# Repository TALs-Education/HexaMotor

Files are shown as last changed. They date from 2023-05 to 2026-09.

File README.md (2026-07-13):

# HexaMotor
### Position & Velocity Control Experiments

## Overview

HexaMotor is a hands-on experimental platform designed for university-level education, emphasizing the nuances of position and velocity control. 
Powered by Simulink, it not only generates the code for the embedded setup but also serves as an intuitive interface. 
This design choice allows students to concentrate on control implementation rather than the intricacies of code writing. 
With a foundation built around a DC motor, HexaMotor offers a tangible experience of system dynamics and control.

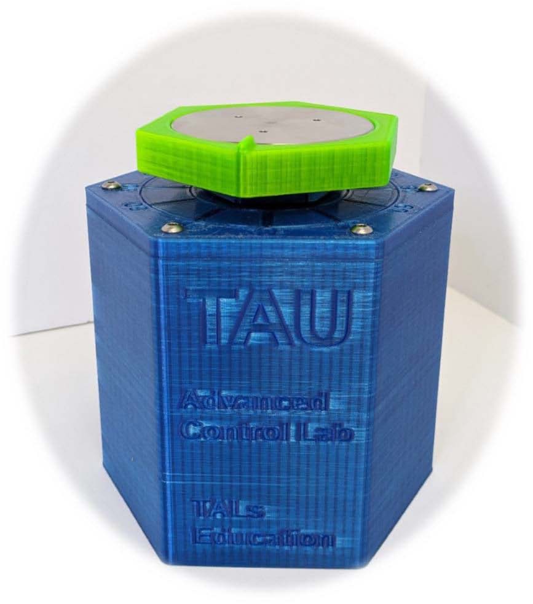
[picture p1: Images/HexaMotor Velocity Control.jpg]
HexaMotor Setup


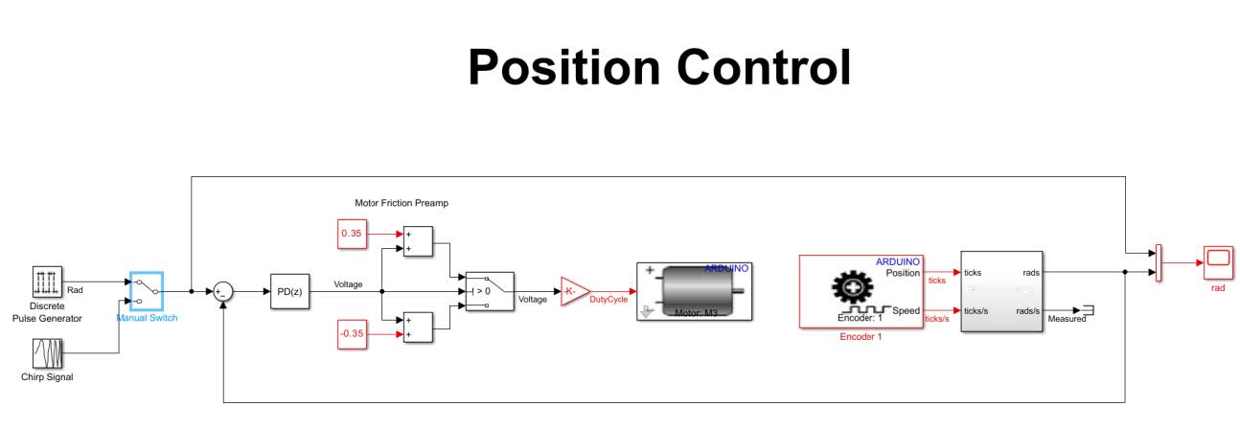
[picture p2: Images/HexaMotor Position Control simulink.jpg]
HexaMotor Simulink Model


## Velocity Control Experiment

### Subjects Covered

- **Introduction to DC Motor Dynamic Equations**
- **Coulomb Friction Identification and Handling**
- **System Identification Using Open Loop Step Response**  
- **System Identification Using Frequency Response**
- **Velocity Control Implementation: Proportional & Proportional-Integral Control Loops**
- **Controller Performance Under Load**

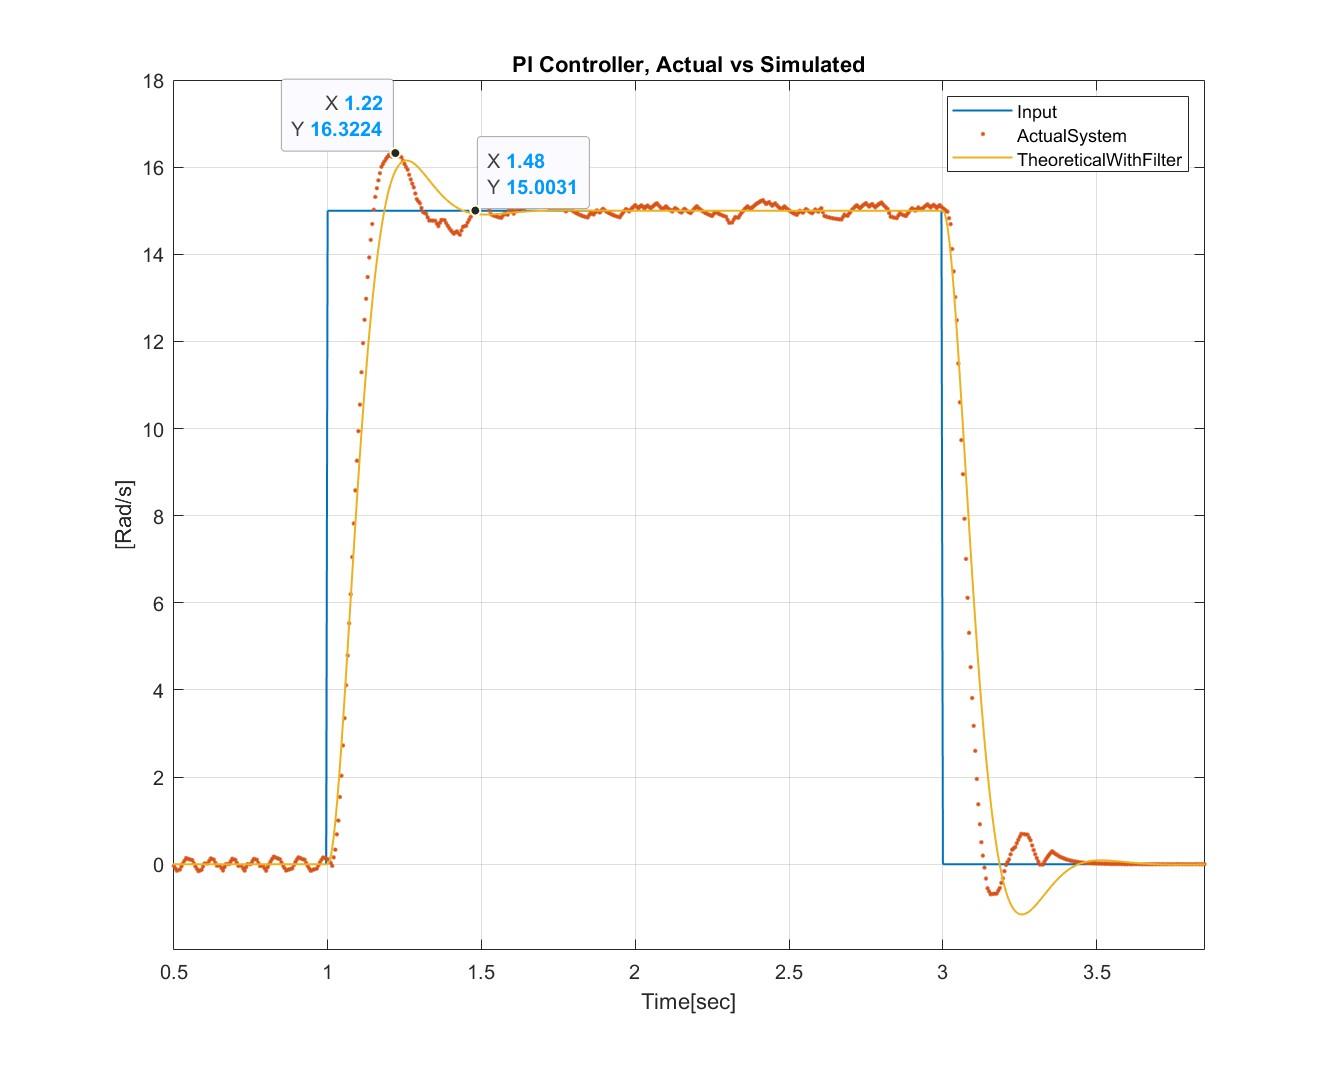
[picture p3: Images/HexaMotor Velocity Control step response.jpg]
Plot for Close Loop Step Response


## Position Control Experiment

### Subjects Covered

- **Introduction to Second Order Systems**
- **Coulomb Friction Identification and Handling**
- **System Identification Using Position Close Loop Step Response**  
- **System Identification Using Position Close Loop Frequency Response**
- **Position Control Implementation Based on Second Order System Modeling**
- **Lead-Lag Compensator Controller Design and Implementation**
- **Force FeedForward Example: Compliant Motor Control**

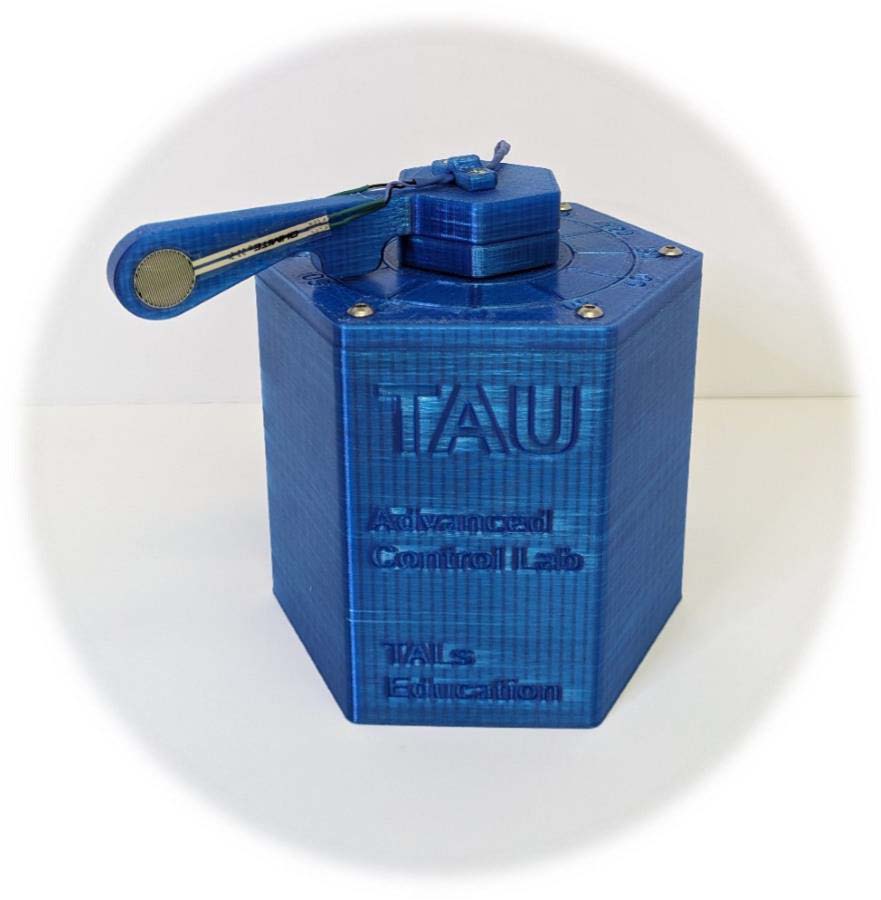
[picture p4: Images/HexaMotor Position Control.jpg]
Force sensor Image
  

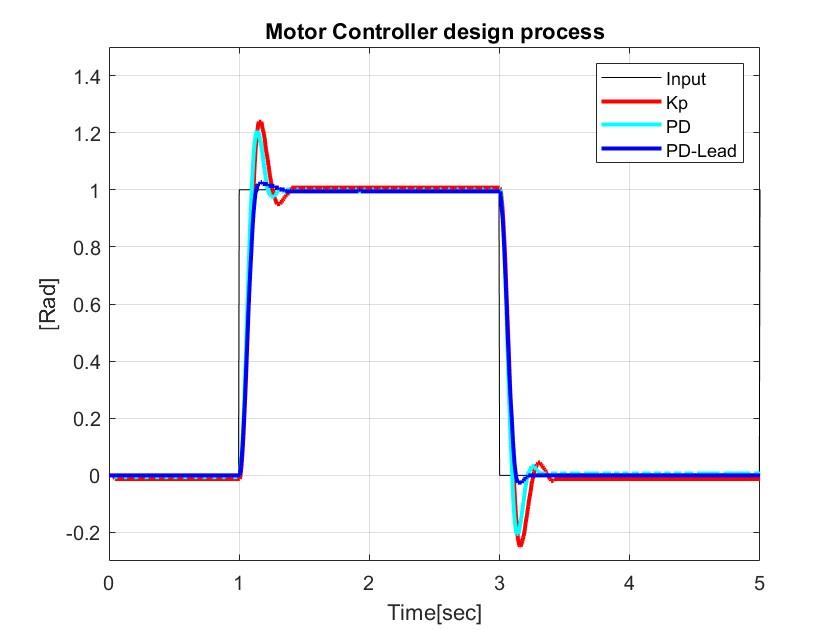
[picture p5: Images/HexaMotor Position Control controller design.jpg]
Plot for Position Close Loop Step Response
  

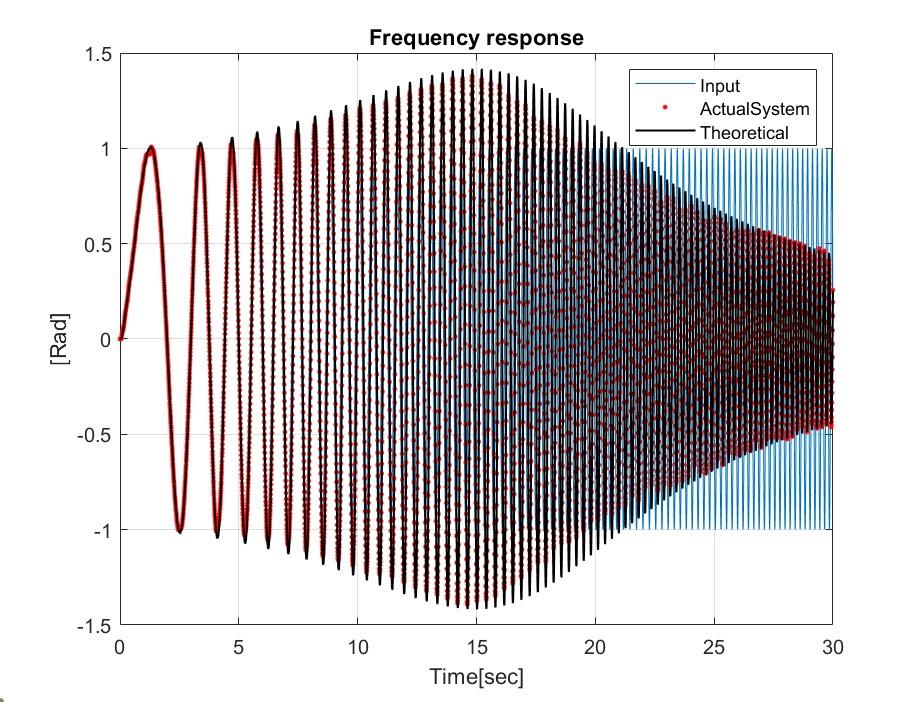
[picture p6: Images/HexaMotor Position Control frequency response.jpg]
Plot for Frequency Response, System Identification
  
  
## Setup & Usage

### 4.1. DC Motor

This gearmotor is a combination of a 12 V brushed DC motor with a 20.4:1 metal spur gearbox. It also incorporates a 48 CPR quadrature encoder on the motor shaft, providing 979.62 counts per revolution of the gearbox’s output shaft.

- **Product page**: [Pololu Gearmotor](https://www.pololu.com/product/4883)
- **Data Sheet**: [Pololu 25D Metal Gearmotors PDF](https://www.pololu.com/file/0J1829/pololu-25d-metal-gearmotors.pdf)

### 4.2. Arduino Boards

The MKR Motor Carrier is an add-on board designed for MKR to control servo, DC, and stepper motors.

- **MKR Zero**: [Arduino MKR Zero Documentation](https://docs.arduino.cc/hardware/mkr-zero)
- **MKR Motor Carrier**: [Arduino Store - MKR Motor Carrier](https://store-usa.arduino.cc/products/arduino-mkr-motor-carrier)

### 4.3. Simulink Support Package

Utilize MATLAB and Simulink Support Packages for Arduino® hardware to interactively communicate with your Arduino. With Simulink, you can also perform model deployment for standalone operations on Arduino boards.

- **MathWorks Support**: [MATLAB & Simulink for Arduino](https://www.mathworks.com/hardware-support/arduino.html)

### 4.4. 3D Model – Fusion360

The entire setup has been designed in Fusion360 as an open-source project meant for educational applications.

- **Fusion360 Project**: [HexaMotor Fusion360 Model](https://a360.co/3Xp2fAi)

### Usage Instructions

For detailed instructions on setting up and running experiments, refer to the provided manuals:

- **Part1: Velocity Control**: [HexaMotor Velocity Control Manual (PDF)](HexaMotor_V01/HexaMotor%20Velocity%20Control.pdf)
- **Part2: Position Control**: [HexaMotor Position Control Manual (PDF)](HexaMotor_V01/HexaMotor%20Position%20Control.pdf)

### Demo Video
- **YouTube:** [HexaMotor Frequency Reponse](https://youtu.be/2T9OHVP0HO0?si=b-_GwjwfcQOfvFEu)

## License

This project is licensed under the GNU General Public License v3.0 - see the [LICENSE](LICENSE) file for details.

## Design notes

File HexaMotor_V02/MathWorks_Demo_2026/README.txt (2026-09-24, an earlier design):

HexaMotor - MathWorks Demo 2026 (MATLAB R2026a)
===============================================

Open this folder as the MATLAB current folder, then run the Live Scripts in this order:

1. HexaMotor_SysID_Demo.mlx       Motor equations, closed-loop 2nd-order identification (chirp sweep),
                                  velocity step Kp=1/Ki=0, PI design for 30 % overshoot at 200 Hz.
                                  Saves the identified model as HexaMotorModel (workspace + HexaMotorModel.mat).
2. HexaMotor_LeadLag_Demo.mlx     Advanced: PD + lead compensator (PM -> 60 deg) on the position loop,
                                  step and frequency responses, Bode shift. Uses HexaMotorModel.
3. HexaMotor_StepVsFreq_Demo.mlx  Sub-demo: open-loop step (bump test) vs. frequency-response identification,
                                  compared with the closed-loop model from demo 1.

Run mode (dropdown at the top of each script):
  Virtual motor / Recorded sweep - no hardware needed (built-in motor emulator; FrequencyResponse.mat is a real recording)
  Hardware                       - builds and runs the Simulink models on the HexaMotor (Monitor & Tune / external mode);
                                   the model and its Scope open and stream live during each run.

Simulink models:  HexaMotor_Position_Control_V02, HexaMotor_Velocity_Control_V02,
                  HexaMotor_LeadLag_Control_V02, HexaMotor_System_Identification_V02
Sample rate:      200 Hz (the scripts set the workspace variable sampleRate = 0.005)
Manuals:          Manuals/  (Velocity Control V02, Position Control V02)
Graphical lead/lag charts from the manual: LeadLag.m

Editing: change the plain-text sources in LiveScriptSources/ and re-save them as .mlx
(in the Live Editor: open the .m file and use Save As > .mlx). Keep only the .mlx files in this
folder: when a .m and a .mlx have the same name in one folder, MATLAB runs the .mlx.

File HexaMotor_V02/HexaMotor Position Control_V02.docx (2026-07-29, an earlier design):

# Position Control

# HexaMotor

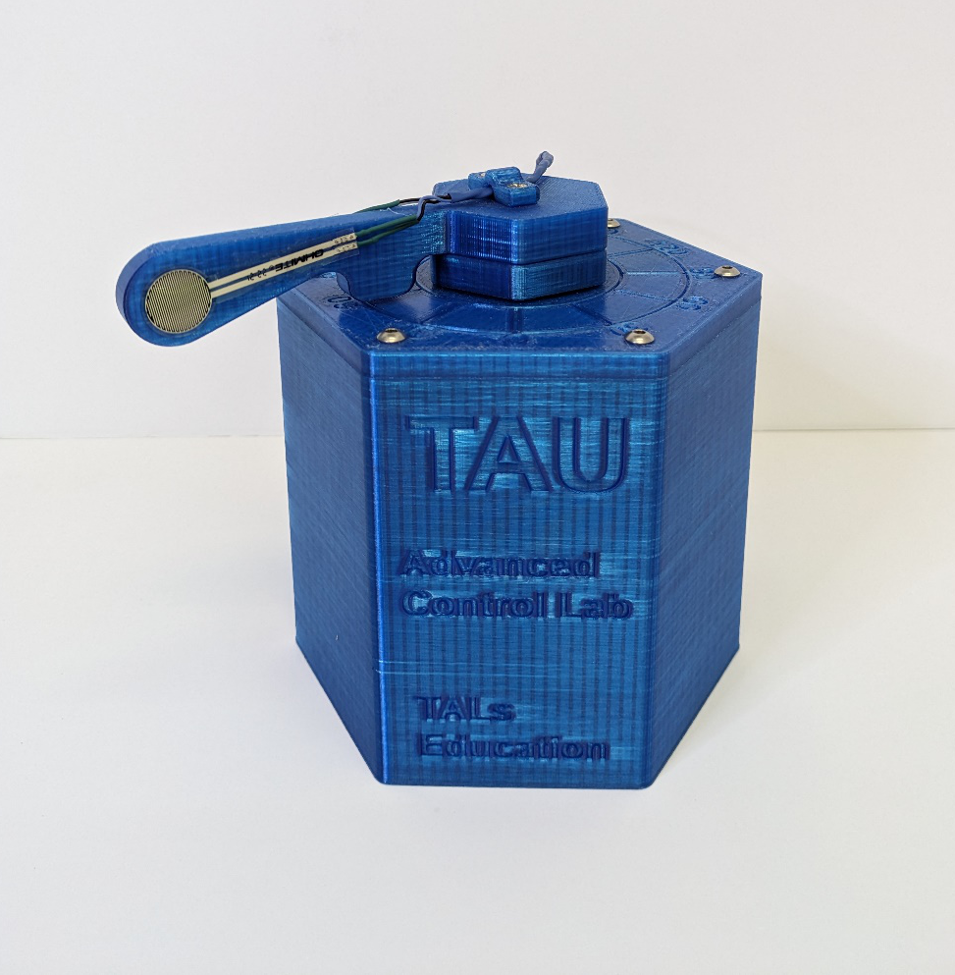
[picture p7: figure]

Experiment objectives:

• Introduction to second order systems.

• Coulomb Friction identification and handling.

• System identification using position close loop step reponse.

• System identification using position close loop frequency reponse.

• Position control implementation based on second order system modeling.

• Lead-Lag compensator controller design and implementation.

# 1. Introduction

In the field of motor control, mastering both velocity and position control is essential for a wide range of applications. While the previous lab experiment delved into the nuances of velocity control and the fundamentals of a DC motor, this experiment pivots to emphasize position control. Position control, vital for accurate maneuvering and precise positioning of mechanisms, demands its own unique approach. This experiment outlines objectives ranging from system identification using step and frequency responses to the design and actual implementation of control strategies.

## First order approximation

While in the previous experiment the full equations of the DC motor were presented and the first-order approximation was derived, in this experiment we will contrinue working with the first-order approximation of the DC motor.

First-Order Transfer Function:

  1.1 G(s)=(K_T)/((RJ)s+(BR+K_T K_b )) ; G(s)=(K_m)/(τs+1)

## Coulomb friction

Recall from the previous experiment that Coulomb friction, which remains constant irrespective of motor speed, contributes to system non-linearity and can pose challenges in control implementation, particularly at low speeds. We identified this friction by applying a controlled voltage to the DC motor, observing the threshold voltage initiating rotation.

## Second order systems

When discussing control systems, a second order system is frequently encountered. It can be described by the standard second-order transfer function:

  1.2 T(s)=K/(s^2 +2ζω_n s+ω_n^2)

Where:

K – is the system static gain.

ω_n – is the undamped natural frequency.

ζ – is the damping ratio.

The system's response is primarily characterized by its damping ratio ζ and natural frequency ω_n

Several performance metrics can be derived from the above standard form:

Percent Overshoot (%OS):

It defines the amount by which the transient response exceeds the steady-state value. For a step response, the percent overshoot is given by: OS=100e^((-πζ)/(√(1- ζ^2))) It should be noted that overshoot occurs only when ζ <1 (underdamped case).

Rise Time (Tr):

The time it takes for the response to rise from 10% to 90% of its final value for an underdamped system. While there's no direct closed-form formula, for many systems with a damping ratio between 0.4 and 0.7, the rise time is approximately: T_r ≈ 1.8/(ω_n)

Settling Time (Ts):

The time for the system response to stay within a certain percentage (usually 2% or 5%) of its final value. It's given by T_s ≈ 4/(ζω_n) for a 2% settling time.

Peak Time (Tp):

The time it takes for the response to reach its first peak. For an underdamped system: T_p = π/(ω_d) where ω_d = ω_n √(1-ζ^2) is the damped frequency.

Natural Frequency ( ω_n ):

It's the frequency at which the system would oscillate if there were no damping (i.e., ζ=0).

## Root Locus

The essence of the root locus lies in its depiction of system dynamics. The locations of the closed-loop poles directly influence the transient response characteristics of the system. By examining the root locus, engineers can predict how changes to the system gain will impact crucial performance metrics such as overshoot, settling time, and oscillation frequency.

The foundation of the root locus method is built on two fundamental principles:

- Magnitude Criterion: At any point on the root locus, the product of the magnitudes of the vectors from all open-loop zeros to that point divided by the product of the magnitudes of vectors from all open-loop poles to that point is equal to 1 (or the gain at that point).
- Angle Criterion: For a point to lie on the root locus, the sum of angles from all open-loop zeros and poles to that point must equal an odd multiple of 180°.

Armed with these criteria, control system engineers can sketch the root locus and use it to select appropriate gains that yield desired closed-loop behavior. Not only does the root locus offer insights into system stability (since poles in the right half of the complex plane denote instability), but it also aids in shaping the system response to meet specified design criteria.

## PID controller

As previously discussed in our prior experimentation, the PID controller is a predominant feedback control algorithm extensively employed in industrial applications due to its efficiacy across diverse scenarios and its systematic tuning methodology.

  1.3 u(t)=K_p e(t)+K_i ∫ e(t)dt+K_d (de(t))/(dt)

The PID controller is characterized by three fundamental components:

Proportional (P): This component yields a control action that is directly proportional to the instantaneous error. The magnitude of this response is governed by the proportional gain

Integral (I): Concerned with the aggregation of error over time, this action aims to nullify any persistent steady-state error.

Derivative (D): This term offers a control action based on the rate of error change, effectively anticipating potential future errors and generating a preemptive control response. In practical applications, a distant pole is introduced to filter out system noise. In our case, the derivative element is filtered by a first-order pole set at half the sampling frequency.

## Lead-Lag Compensator

Lead and lag compensators are essential tools in control theory, particularly in the design of feedback control systems to meet transient and steady-state response specifications:

Lag Compensator: The general transfer function for a lag compensator can be described as:

  1.4 G_(Lag) = (1+τs)/(1+aτs)

Where τ is the time constant and a>1.

Purpose: The primary purpose of a lag compensator is to improve the steady-state response of the system. This is done by adding a pole and a zero to the system. Since the zero is closer to the origin than the pole, the compensator will have a magnitude less than one for most frequencies, thereby reducing the gain of the system and the steady-state error.

Placement: The zero is placed to the left of the pole. The distance between them determines the magnitude of the phase boost, but a lag compensator will not introduce a significant phase lead.

Drawbacks: Lag compensators generally degrade the transient response because they tend to reduce the system bandwidth.

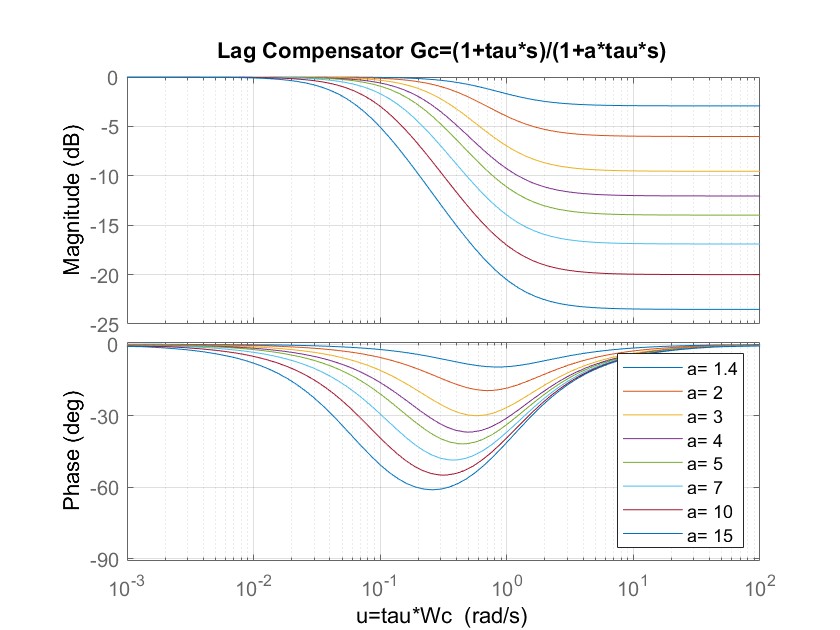
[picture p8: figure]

Figure 1 Lag Compensator plot using LeadLad.m scrip

Lead Compensator: The general transfer function for a lead compensator can be described as:

  1.5 G_(Lead) = (1+aτs)/(1+τs)

Where τ is the time constant and a>1

Purpose: The primary purpose of a lead compensator is to improve the transient response of the system. By placing a pole and a zero in the left half plane, it introduces phase lead to the system, which can be used to reshape the root locus or push the closed-loop poles to desired locations.

Placement: The zero is placed to the right of the pole, introducing phase lead in the frequency range of interest. The amount of phase lead is determined by the distance between the pole and zero and their proximity to the imaginary axis.

Drawbacks: Because of the introduced phase lead, a lead compensator also increases the gain in some frequency range. This can make the steady-state error worse.

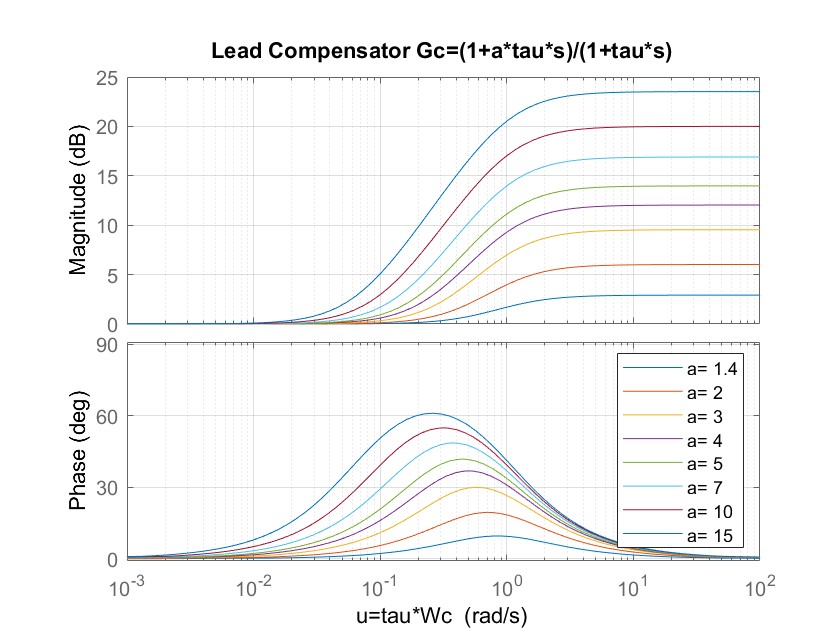
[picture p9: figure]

Figure 2 Lead Compensator plot using LeadLad.m scrip

Design Considerations:

Lag: When using a lag compensator, the goal is often to place the pole and zero sufficiently far from the imaginary axis, so they don't affect the transient response. You place the zero so that the magnitude of the system is unchanged at the crossover frequency.

Lead: When designing with a lead compensator, the goal is often to add enough phase lead to achieve desired transient characteristics without pushing the gain crossover frequency too high.

In practice, combining both lead and lag compensators can offer an optimal balance between steady-state and transient performance in many systems.

Graphical approach for Lead Lag design:

Run the "LeadLag.m"

- The script "LeadLag.m" generates plots associated with the lead-lag compensator design. This includes various curves representing different amounts of phase lead and the corresponding gains for different values of a (since a lead compensator's behavior is determined by its zero and pole locations, which are in turn determined by the parameter a and the time constant τ).

Open-Loop Bode Plot:

- Start by plotting the open-loop Bode plot of the system. From this plot, you'll identify the current crossover frequency ω_c and the existing phase margin.

Determine Required Phase Boost:

- Based on system specifications or desired closed-loop performance, determine how much additional phase you want to introduce.

Iterative Process for Design:

- Use the provided lead graph (generated by the script) to identify a point that provides the necessary phase boost.
- From the corresponding gain graph, note the gain added due to the lead compensator.
- This added gain will shift ω_c in the open-loop Bode plot.
- Now, with this new ω_c the phase requirements might be slightly different. So, you may need to iterate this process to ensure that the final selected values of phase and gain boosts provide the desired performance.

Calculate the Lead Compensator:

- Using the relationship and the equation provided: G_(Lead) (s)=(1+aτs)/(1+τs)
- And given: τ= u/(ω_c) Where:
- τ is the time constant of the lead compensator.
- a is the gain boost and defines the curve.
- u is the specific point on the curve/graph which dictates the amount of phase lead and gain boost introduced.
- ω_c is the new crossover frequency after introducing the compensator.

Implement and Test:

- Once the lead compensator parameters are determined, you can then apply them to the system and validate if the system's response matches your design specifications. You may also need to iterate the design process if the initial compensator doesn't provide the desired results.

This process essentially allows you to design a lead compensator using graphical methods, taking advantage of the insight provided by Bode plots and the relationships between phase lead, gain boost, and compensator parameters.

# 2. Pre Lab

## Second order system identification

Identifying the First Order Transfer Function of a DC Motor Using Closed-Loop Step Response in Position Feedback

In this method, the behavior of the DC motor under position feedback is contrasted with a canonical second-order system, described by T(s)=K/(s^2 +2ζω_n s+ω_n^2) . The benefits of this comparison are twofold. Firstly, second-order systems are thoroughly understood and have been extensively studied, offering a benchmark against which the motor's dynamics can be evaluated. Secondly, essential performance metrics — including overshoot, peak time, rise time, and settling time — can be directly correlated to the system's damping ratio, ζ, and its natural frequency, ω_n .

Armed with these metrics from experimental observations and a known feedback gain, it's possible to determine the inherent characteristics of the DC motor, especially its time constant, τ, and gain, k_m .

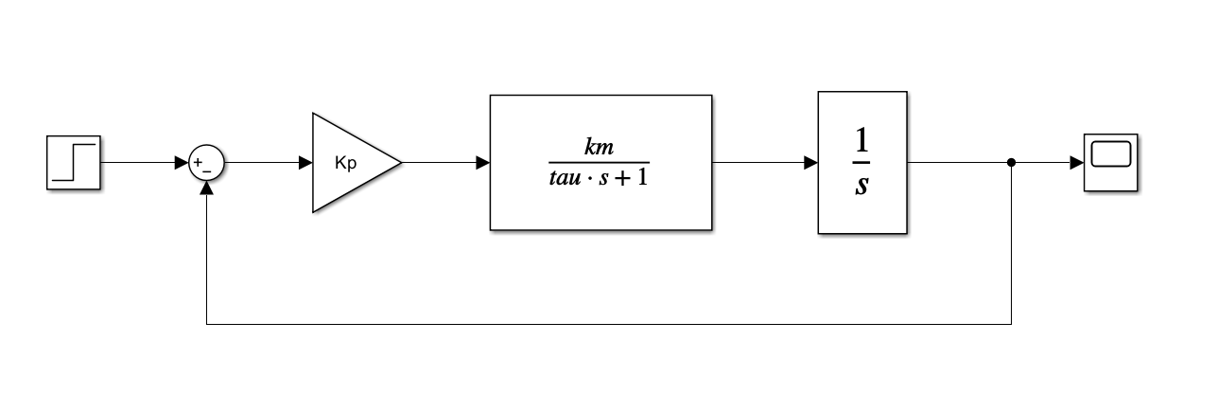
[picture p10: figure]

Figure 3 Simulink model representing close loop system

a. Given the system above, assuming the plant is a DC motor using its first order approximation G(s)=(k_m)/(τs+1) , write what the blocks represent and the units of the input and output signals.
b. Given the system above, what is the close loop transfer function:
c. Compare the transfer function derived in b. To the standard second order transfer function of the form T(s)=K/(s^2 +2ζω_n s+ω_n^2) . Find representations of ζ and ω_n as a function of τ , k_m and Kp
d. Using Matlab, plot the step response of the following first order system G(s)=2.5/(0.1s+1) , using the system represented above with gain of Kp=10.
e. Based on the peak time and over-shoot performance metrices for a standard second order system. Find the values of ζ and ω_n .
f. Based on the equations derived in C verify the transfer function of the DC motor in the form of G(s)=(k_m)/(τs+1)
g. Using root locus plot for the DC motor transfer function G verify that the over-shoot, ζ and ω_n for Kp=10 is the same as measured and calculated in d,e (up to a small rounding error). explain how root locus can be beneficial in designing a proportional controller.

## PD controller

Tuning a PD Controller for a DC Motor Using Canonical Second-Order Transfer Function Analysis

In this approach, the behavior of the DC motor, when coupled with a PD controller, is compared with a canonical second-order system described by T(s)=K/(s^2 +2ζω_n s+ω_n^2) . Such a comparison offers two primary advantages. Firstly, the canonical second-order systems serve as a well-defined benchmark, given their extensive study and well-understood dynamics. Secondly, by mapping desired system response characteristics, such as overshoot (OS) and peak time, to the parameters of this second-order system, one can directly relate them to the controller gains, Kp and Kd.

Through this method, it becomes possible not only to tune the PD controller for a specific DC motor but also to have a systematic approach to achieving desired dynamic characteristics. By tailoring Kp and Kd based on the insights from the second-order comparison, one can design a controller that meets specific performance metrics, paving the way for optimal system operation.

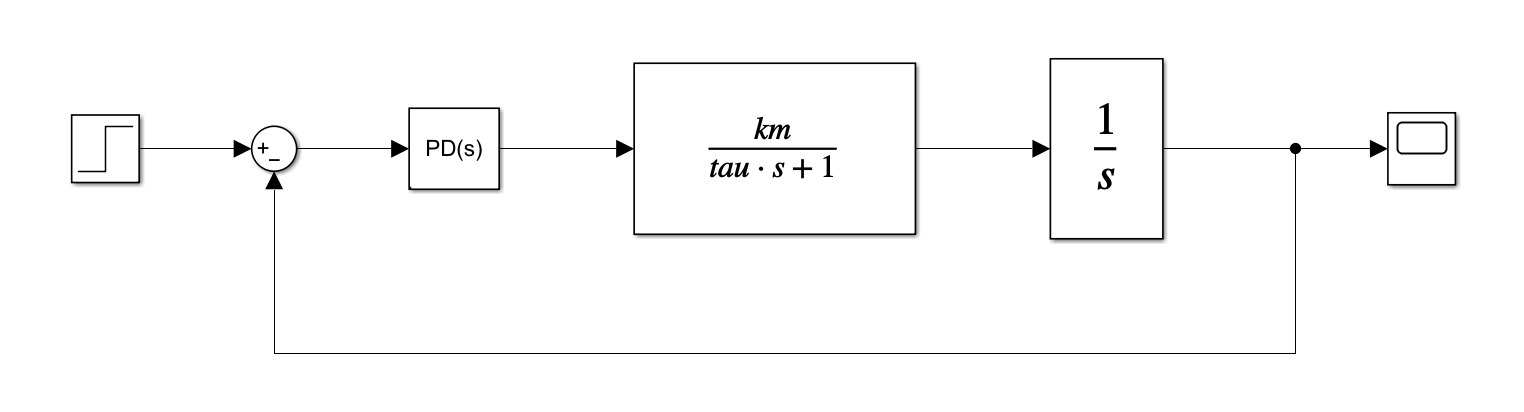
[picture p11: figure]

Figure 4 Simulink model representing close loop system

a. Given the system above, assuming the plant is a DC motor using its first order approximation G(s)=(k_m)/(τs+1) , and PD(s) ( is a proportional derevative controller) of the form:

PD(s)=k_p +k_d s . What would be the close loop transfer function T_1 (s) .

b. Compare the poles of the transfer function T_1 (s) to the poles of the standard second order system represented as T_2 (s)=K/(s^2 +2ζω_n s+ω_n^2) . And find representation of ζ and ω_n as a function of k_m , τ, k_p and k_d .
c. Find the values of ζ and ω_n which will result in a step response for the standard second order system T_2 (s)=K/(s^2 +2ζω_n s+ω_n^2) with the following criteria: %OS of 25% and T_p =0.20 [seconds] .
d. Based on the equations found in b. And assuming the motor has a transfer function of

G(s)=2.5/(0.1s+1) find the values for k_p and k_d .

e. Simulate the system at a. (in matlab or simulink). using the found controller gains and dc motor transfer function from d. What can you say about its %OS, T_p ? why is it slightly different from the designed OS%, T_p . Plot the step response of the system and mark OS%, T_p .

## Lead-Lag compensator

Graphical Approach to Lead-Lag Compensator Design for DC Motor Performance Enhancement Using Bode Plots

By graphically analyzing the Bode plots, one can visually discern the system's frequency response shortcomings. The "lead" in the compensator can be tailored to boost phase margin and speed up system response, while the "lag" part can be optimized to improve steady-state accuracy. Through a methodical graphical approach, not only is it possible to pinpoint where compensation is needed but also to sketch the compensator's frequency response right on the Bode plot, ensuring an intuitive and interactive design process.

Figure 5 Simulink model representing close loop system

a. Given the system above, and using the values from the previous section, plot in matlab the open loop bode of the system ( PD(s)∙P(s) whereas P(s)=(k_m)/(s(τs+1)) )and evaluate the ω_c (crossover frequency) and phase margin of the system.
b. Design a lead lag compensator to fix the Phase margin to 60° . Add to the bode plot in a. the compesated bode and mark the new ω_c , Phase margin. Plot the step responses from both of the systems on the same graph. Mark the OS%, T_p . Of both. (use the graphical method or any other method of your choice).

# 3. In Lab

## Introduction

Welcome back to the lab! Before diving into our experiments, please take a moment to reacquaint yourself with our hardware. You'll be using the HexaMotor setup, which features a DC motor paired with an encoder and linked to an Arduino MKR motor controller. You can operate it through Matlab Simulink. For more details, refer to the appendix of this manual.Start by opening Matlab R2022b

- Navigate to …\Documents\MATLAB
- Create a new folder with your name and copy the lab materials into it
- Open “HexaMotor_MotorTest_V02.slx” Simulink model.
- Prior to running the model make sure the setup is connected to the PC through USB cable and the power supply is connected to the socket.
- Press the On/Off Button at the back and make sure the light is on.
- Make sure the rotating mass is present. (same configuration as in the velocity control experiment)
- Under hardware you will find the Monitor&Tune button, press it, if everything is properly set it will compile the Simulink model and upload a C++ code to the micro controller. When the process has finished the button with be switch to a stop button and at the button bar a simulation time will start counting.

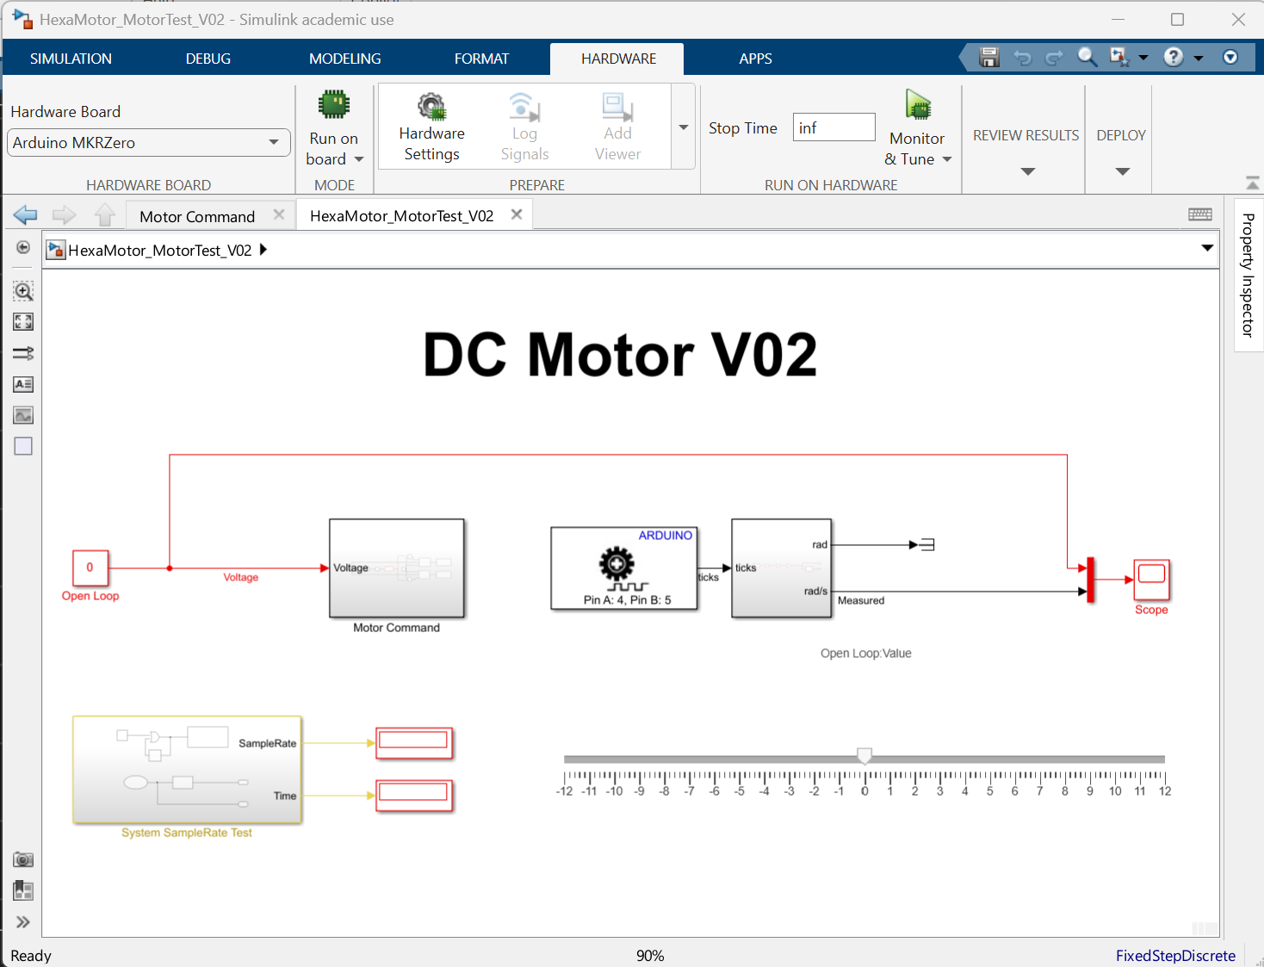
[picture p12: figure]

Figure 6 Simulink model for interaction with the HexaMotor Setup

## Revisiting Coulomb Friction

Let's delve deeper into the system by reexamining the Coulomb friction present. Often termed 'dry friction', Coulomb friction consistently opposes motion and remains unaffected by the varying velocity between surfaces. Within a brushed DC motor's framework, this is perceived as the Dead-Zone. This Dead-Zone denotes the area where, despite voltage being administered, the motor remains static. This immobility arises primarily when the exerted voltage or torque falls short of conquering the system's innate static friction. Pinpointing and rectifying this Dead-Zone is pivotal for the motor's seamless operation, especially during its initial phases and at slower speeds.

- Using the same “HexaMotor_MotorTest_V02.slx” Simulink model. Find the minimum voltage values required to start the motor motion. You can change the slider range if you wish to use it to find the minimal values.

You can push the motor a bit with your hand and try to find the least resistance angle. (due to the non-linearity in the friction mentioned earlier).

- Write those values for next section.

## Step response modeling

Let's now transition to our next experiment: exploring the first order transfer function of a DC motor using the closed-loop step response in position feedback.

- Open the “HexaMotor_Position_Control_V02.slx” Simulink model. Make sure the switch is set to Pulse Generator input.
- Update the Motor Friction Preamp gains with the values found in the previous section.
- Adjust the PD controller to proportional only with kp=10 and update stop time to 30 seconds.
- Run the experiment

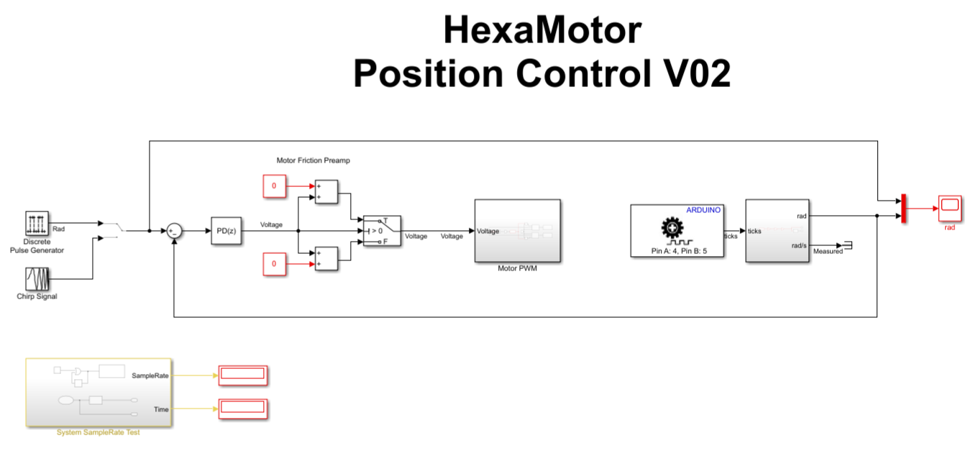
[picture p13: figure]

Figure 7 Simulink model : "HexaMotor_Position_Control_V02.slx”

For the Report:

a. Using the closed-loop step response, estimate the DC motor's transfer function following the method previously described and practiced in the pre-lab section.
b. Create a plot in Matlab which contains the response from the recordings and as a simulation using the lsim function in Matlab for the identified transfer function. Mark peak time and over-shoot values for both signals.

Hint: use the following Matlab commands: (do not forget to update the transfer function and add grid, axis labels, title to the plot).

% Generate plots from recordings and simulated transfer function

s=tf('s');

Kp = 10;

G = 2.5/(0.1*s+1)/s; % update the transfer function values

figure(1)

plot(ScopeData.time,ScopeData.signals.values(:,1))

hold on

plot(ScopeData.time,ScopeData.signals.values(:,2),'.');

[y,t] = lsim(Kp*G/(1+Kp*G),ScopeData.signals.values(:,1),ScopeData.time);

plot(t,y);

hold off

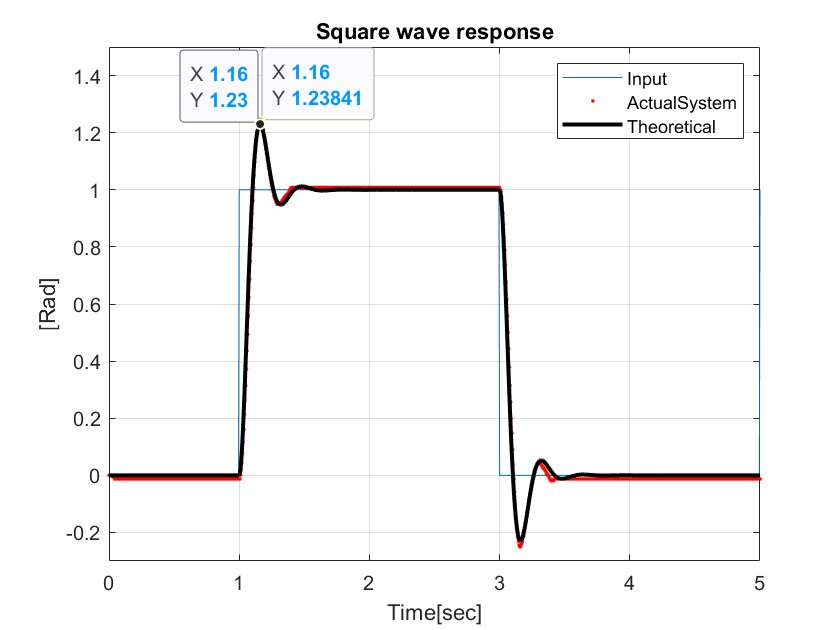
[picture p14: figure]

Figure 8 Square wave response, actual system and simulated model

## Frequency response modeling

In this section, we'll utilize a frequency response from a chirp signal to determine the second order system's transfer function. From this, we can then derive the first order transfer function of the DC motor, employing the same approach as outlined in the preceding section.

- Using the same “HexaMotor_Position_Control_V02.slx” Simulink model. Move the switch to a chirp input.
- Run the experiment.

For the Report:

a. Utilize the closed-loop chirp response to estimate the second order system's transfer function using the 'tfest' function in MATLAB. Then, estimate the DC motor's transfer function based on the approach we previously outlined and practiced in the pre-lab section.

Hint: use the following Matlab commands:

grid, axis labels, title to the plot).

% Estimate transfer function

s=tf('s');

data = iddata(ScopeData.signals.values(:,2),ScopeData.signals.values(:,1),0.002);

T=tfest(data,2,0)

b. Create a plot in Matlab which contains the response from the recordings and as a simulation using the lsim function in Matlab for the identified transfer function.

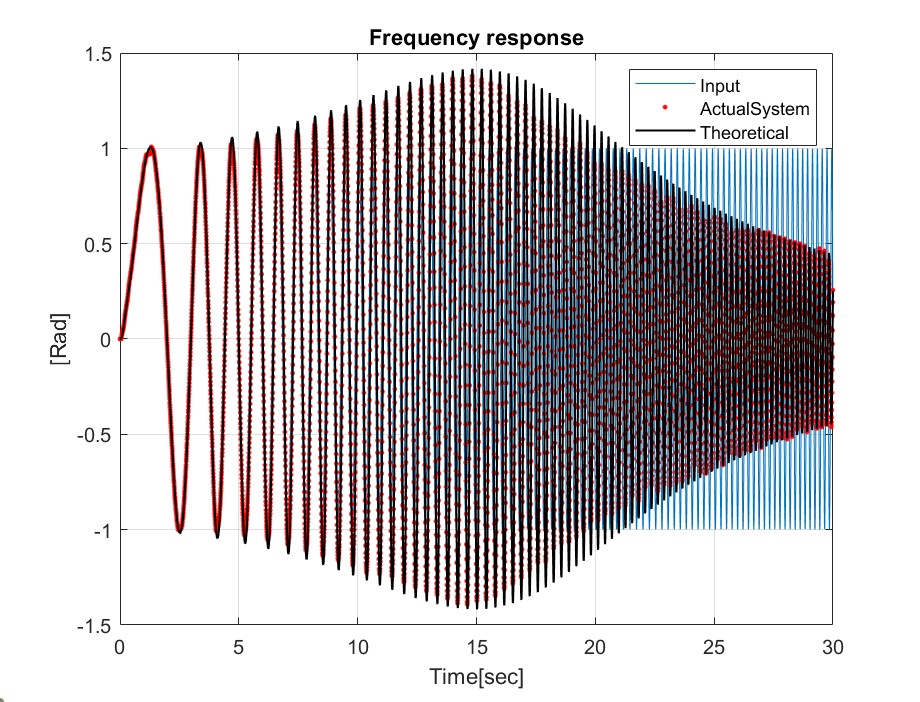
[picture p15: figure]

Figure 9 Frequency response, actual system and simulated model

## PD controller

In this section, drawing on the approach used in the pre-lab section and based on the transfer function previously determined using the frequency response, we will harness the characteristics of a canonical second-order transfer function. Our objective is to design a PD controller tailored to meet specific criteria: an overshoot (OS) of 25% and a peak time (Tp) of 0.15 seconds.

- Using the same “HexaMotor_Position_Control_V02.slx” Simulink model. Move the switch to Pulse Generator input.
- using the approach from the pre lab section calculate the Kp and Kd. Of the PD controller and update its values in simulink, (Use the motor transfer function found using the frequency response system identifcation method).
- Run the experiment.

For the Report:

a. Create a plot in Matlab which contains the response from the recordings and as a simulation using the lsim function in Matlab for the identified transfer function and the calculated PD controller.

Mark peak time and over-shoot values for both signals.

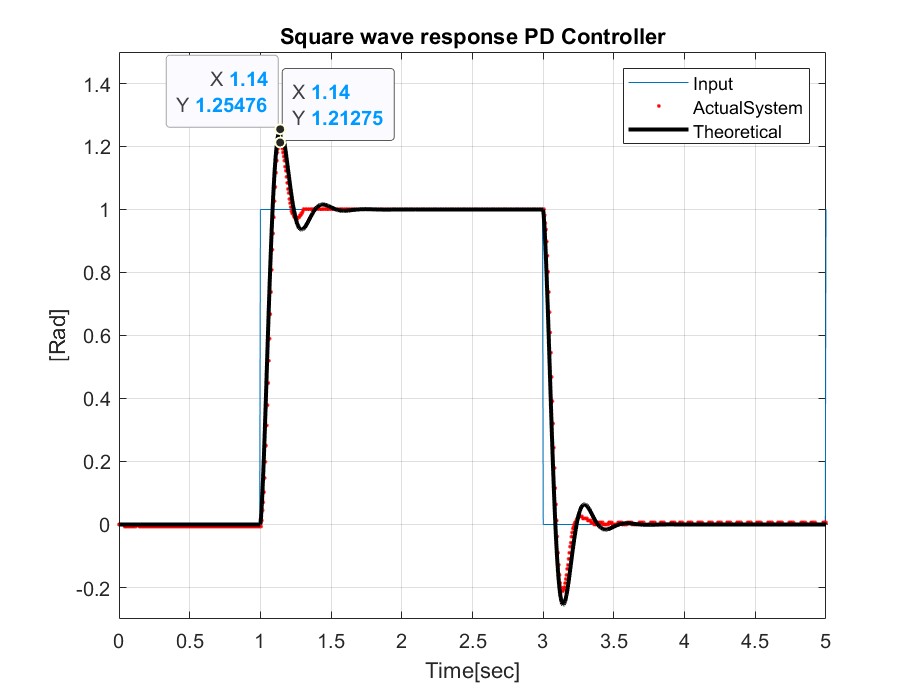
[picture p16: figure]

Figure 10 Square wave response with a PD controller, actual system and simulated model

## Lead-Lag Compensator

In this section, we'll introduce a lead-lag compensator to enhance the motor's response. Employing the approach adopted in the pre-lab section, our aim is to refine the system's phase margin to 60° .

- Open the “HexaMotor_LeadLag_Control_V02.slx” Simulink model. Make sure the switch is set to Pulse Generator input.
- Using the approach from the pre lab section calculate the necessary Lead compensator and update its values in the simulink Lead-Lag block.
- Update the PD controller values to the ones found in the lab
- Run the experiment.

For the Report:

a. Present your calculations and illustrate the variations in the system's Bode plot.
b. Create a plot in Matlab which contains the response from the recordings and as a simulation using the lsim function in Matlab. Mark peak time and over-shoot values for both signals.

Bonus: Redo the experiments and record the response of the system with the Pulse generator signal for the following controllers:

- Proportional gain only kp=10,
- PD controller found in the lab.
- LeadLag Controller with the PD controller.

Plot on the same plot the response from the 3 recordings. Make your conclusion regarding the performance of the designed controller.

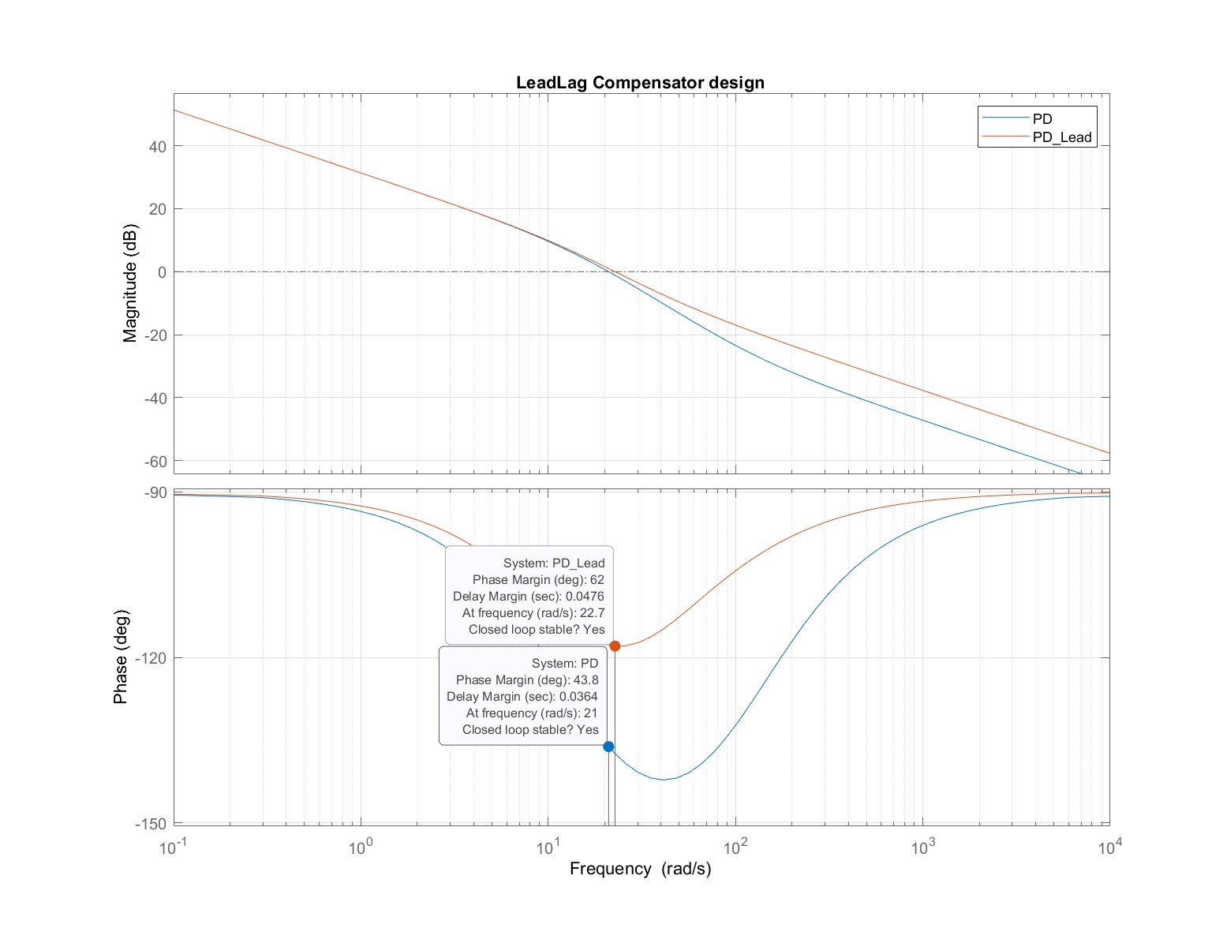
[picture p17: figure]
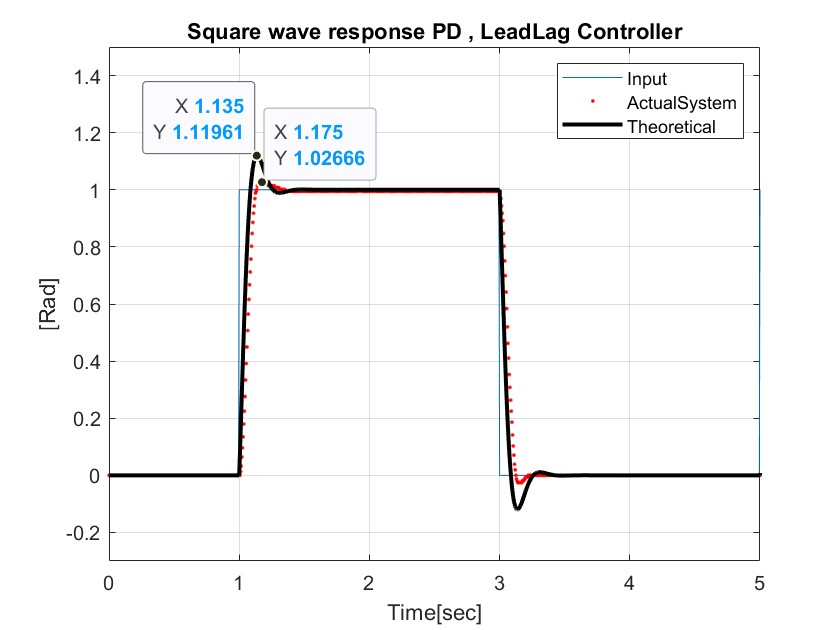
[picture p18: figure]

Figure 11 LeadLag design and system response

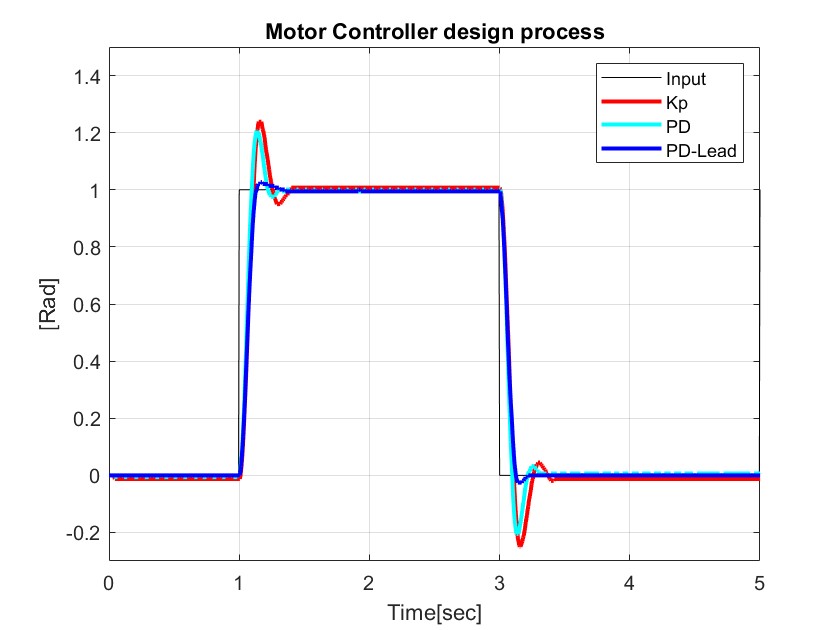
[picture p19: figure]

Figure 12 Controller design process, Square wave response of various controllers

Don't forget to turn off the system at the end of the experiment using the switch cable

# 4. Appendix

Github Page: https://github.com/TALs-Education/HexaMotor

## DC Motor

This gearmotor consists of a low-power, 12 V brushed DC motor combined with a 20.4:1 metal spur gearbox, and it has an integrated 48 CPR quadrature encoder on the motor shaft, which provides 979.62 counts per revolution of the gearbox’s output shaft.

Product page: https://www.pololu.com/product/4883

Data Sheet: https://www.pololu.com/file/0J1829/pololu-25d-metal-gearmotors.pdf

## Arduino board / Motor Driver

The MKR Zero board is used with a motor driver to drive the motor and read the encoders.

MKR Zero: https://docs.arduino.cc/hardware/mkr-zero

MP6550 Brushed DC Motor Driver: https://www.pololu.com/product/4733

## Simulink Support package

With MATLAB and Simulink Support Packages for Arduino® hardware, you can use MATLAB and Simulink to interactively communicate with your Arduino. Simulink also enables you to perform model deployment for standalone operations on Arduino boards.

MathWorks: https://www.mathworks.com/hardware-support/arduino.html

## 3D Model – Fusion360

The setup is design in Fusion360 as an open source project, for educational purposes. Available at:

Fusion360: https://a360.co/4fCxmAJ

The Iby and Aladar Fleischman Faculty of Engineering Tel Aviv University

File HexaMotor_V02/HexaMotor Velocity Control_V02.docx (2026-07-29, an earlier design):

# Velocity Control

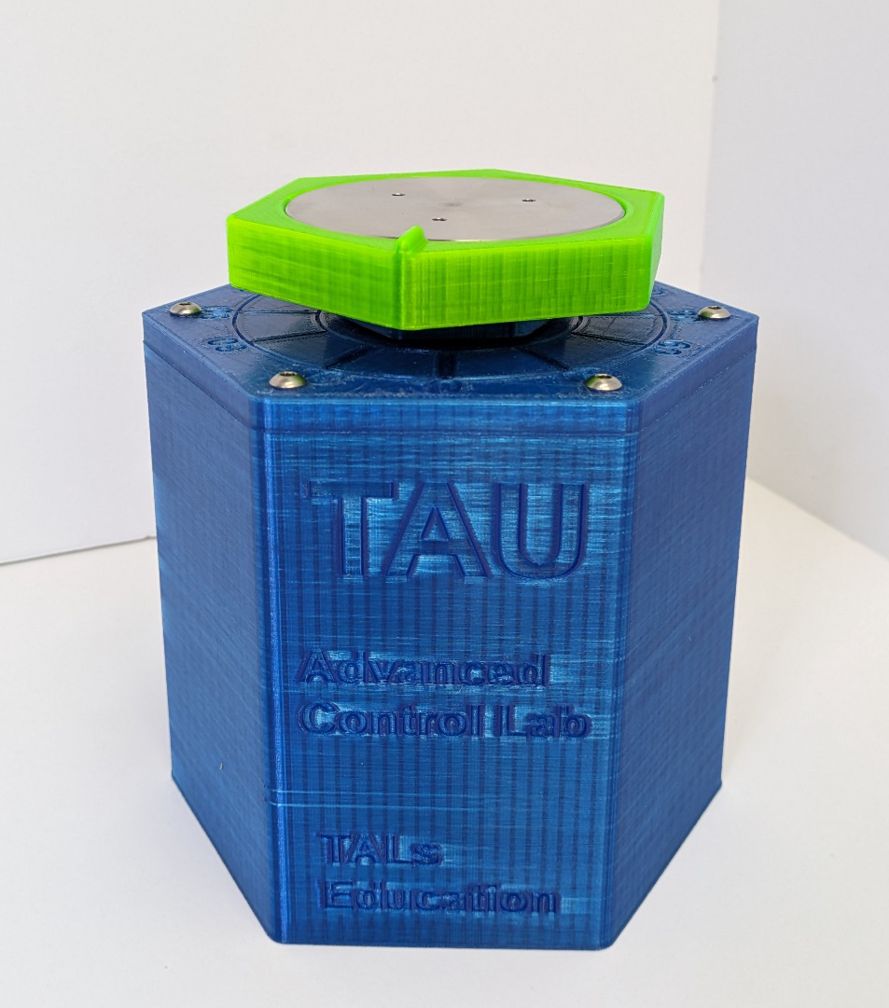
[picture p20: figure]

# HexaMotor

Experiment objectives:

• Introduction to DC motor dynamic equations.

• Coulomb Friction identification and handling

• System identification using open loop step response, model validation.

• System identification using frequency response, model validation.

• Velocity control implementation. Proportional, Proportional - Integral control loops.

• Controller performance under load.

# 1. Introduction

DC motors are electromechanical devices that convert electrical energy into mechanical energy, using principles of electromagnetism. They are known for their simple construction, high reliability, and ease of control. These features make them suitable for various applications, from small electronic devices to large industrial machinery.

## DC motor equations

The electric equivalent circuit of the armature and the free-body diagram of the rotor are shown in Figure 1.

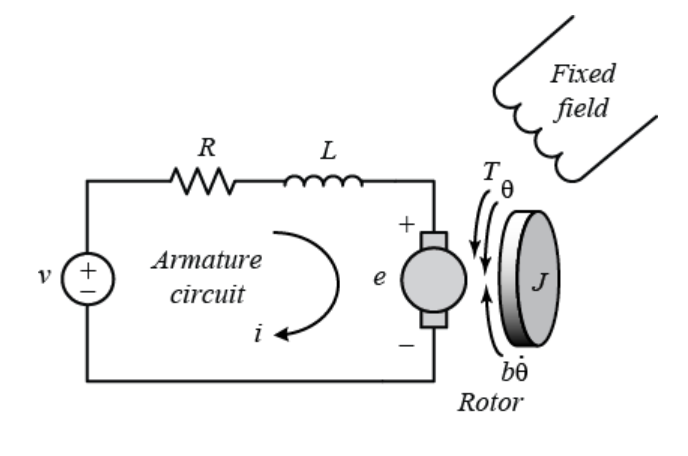
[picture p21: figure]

Figure 1: Electric equivalent circuit of a dc motor

V - Applied Voltage: The voltage applied across the motor's terminals. It is the input to the system and determines the driving force behind the motor.

i - Armature Current: The current flowing through the armature winding, responsible for creating the magnetic field that drives the motor.

R - Armature Resistance: The resistance of the armature winding, which opposes the flow of current.

L - Armature Inductance: The inductance of the armature winding, which determines how quickly the current can change in the coil.

V_(emf) - Back Electromotive Force (EMF): Voltage generated by the motor's rotation, opposing the applied voltage.

K_T - Torque Constant: A factor that relates the motor's torque output to its current. It depends on the motor's construction.

K_b - Back EMF Constant: A factor that relates the motor's back EMF to the angular velocity. It often equals the torque constant in many DC motors.

T - Torque: The twisting force exerted by the motor on its shaft.

T_(friction) - Friction Torque: The torque opposing the motor's rotation due to various frictional effects.

J - Moment of Inertia: A measure of the motor's resistance to changes in its rotational speed. It depends on the distribution of mass in the rotating parts.

ω - Angular Velocity: The rate of rotation of the motor's shaft, often the controlled output in velocity control systems.

B - Damping Coefficient: A parameter representing the viscous friction in the system. It characterizes how the frictional forces are proportional to the angular velocity.

T_(coulomb) - Coulomb friction.

s - Complex Frequency (Laplace Variable): In the context of the transfer function, s is a complex variable used in the Laplace transform.

Voltage Equation:

  1.1 V=Ri+L(di)/(dt)+K_b ω

where V is the applied voltage, R is the armature resistance, i is the armature current, L is the armature inductance, K_b is the back EMF constant, and ω is the angular velocity.

Torque Equation:

  1.2 T=K_T i-T_(friction) - J(dω)/(dt)

where T is the torque, K_T is the torque constant, T_(friction) is the friction torque, J is the moment of inertia, and (dω)/(dt) is the angular acceleration.

Friction Model:

  1.3 T_(friction) =Bω+T_(coulomb)

By substituting the expressions for torque and friction into the torque equation and solving for the differential equation relating the applied voltage to the angular velocity, we obtain:

  1.4 LJ(d^2 ω)/(dt^2)+(RJ+BL)(dω)/(dt)+(BR+K_T K_b )ω=K_T V

Now, the transfer function relating the applied voltage V(s) to the angular velocity Ω(s) in the Laplace domain (assuming zero initial conditions) is:

  1.5 G(s)=(K_T)/(LJs^2 +(Rj+BL)s+(BR+K_T K_b ))

## First order approximation:

Armature Inductance (L): The inductive term L(di)/(dt) in the voltage equation is often neglected. This is under the assumption that the armature inductance is small compared to the resistance, meaning that the electrical dynamics are much faster than the mechanical dynamics.

First-Order Transfer Function:

  1.6 G(s)=(K_T)/((RJ)s+(BR+K_T K_b ))

This first-order model offers a simpler representation of the DC motor's dynamics and is useful for preliminary control design or when the details of the electrical subsystem are not critical. It captures the main characteristics of the motor's velocity response but omits some of the subtler dynamics present in the full second-order model.

For additional reading consider the following links:

DC motor velocity model:

https://ctms.engin.umich.edu/CTMS/index.php?example=MotorSpeed&section=SystemModeling

System analysis:

https://ctms.engin.umich.edu/CTMS/index.php?example=MotorSpeed&section=SystemAnalysis

## Coulomb friction

Coulomb friction is distinctive from viscous damping, as it remains constant regardless of the speed of the motor. It contributes to non-linearity in the system and can lead to challenges in maintaining precise control, especially at low speeds.

Measuring Coulomb friction in a DC motor is essential for designing effective control strategies. One common method to identify this friction involves applying a small, controlled voltage to the motor and observing the threshold voltage at which the motor begins to rotate. By relating this threshold voltage to the known torque-to-current relationship, the Coulomb friction torque can be quantified.

## Step response modeling

Step response modeling, commonly referred to as the "bump test," is a straightforward examination grounded in the step response characteristics of a stable system. In this test, a step input is applied to the system, and the subsequent response is observed and recorded. To illustrate this concept, imagine a system defined by a particular transfer function:

  1.7 G(s)=K/(τs+1)

The step response in the shown figure is generated using K=10 rad/V and τ=0.1s .

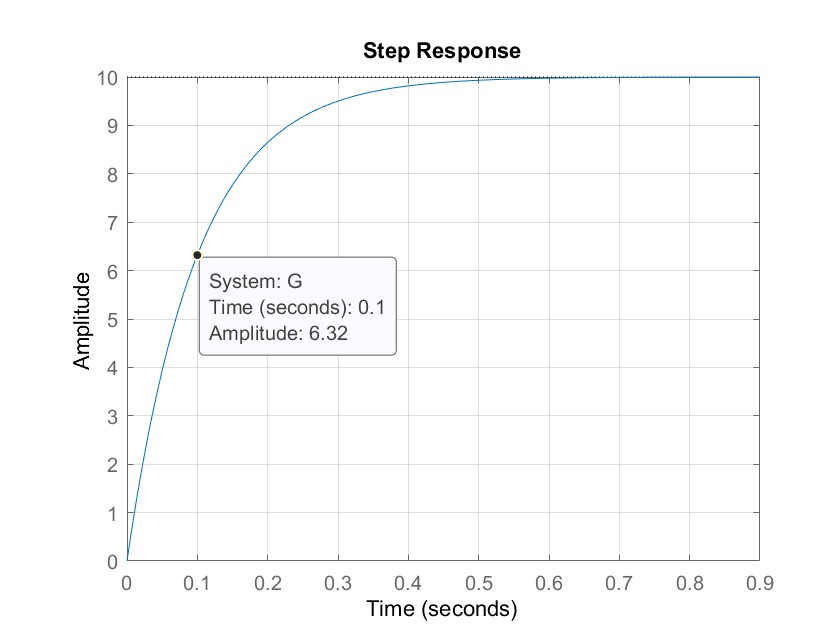
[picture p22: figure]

Figure 2 Step response of eq1.7 with K=10, τ=0.05s.

The time constant τ is a measure of how fast the system responds to a change in input. It's defined as the time it takes for the system's response to reach approximately 63.2% of its final value (steady-state value) after a step change in input.

To see why it is the case lets evaluate a first-order linear system that has the general form of a time constant τ and can be described by the following first-order differential equation:

  1.8 τ(dy(t))/(dt)+y(t)=Ku(t)

If the system is subjected to a step input of magnitude A, the response y(t) can be described by:

  1.9 y(t)=KA(1-e^(-t/τ) )

By evaluation the response at t=τ we get:

  1.10 y(τ)=KA(1-e^(-τ/τ) )≈KA∙0.632

## Frequency response modeling

System analysis with a sinusoidal input provides insights into the motor's frequency response, resonance behavior, and the effect of damping. The motor's transfer function can be used to investigate how different frequencies of the sinusoidal input are amplified or attenuated, revealing information about the stability, bandwidth, and transient response of the system.

When a sine wave is used as an input for a DC motor, the motor's output results in a sinusoid of the same frequency but is scaled and delayed as by the frequency response theorem. As illustrated in Figure 3, the length of one full period of the sinusoid is represented by t1, while t2 indicates the time delay between the input voltage signal Vm, and the corresponding scaled output speed signal, ω_m .

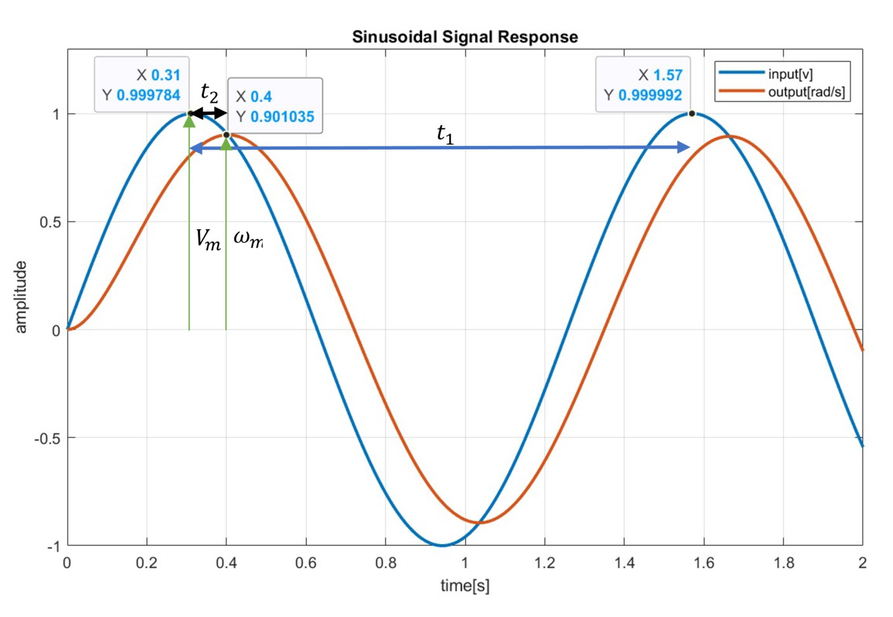
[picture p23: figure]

Figure 3 System response with a sinusoidal signal

The magnitude response of the resulting output changes with respect to the frequency of the applied sinusoid and can be used to find the time constant τ of the DC motor with the first order approximation. In addition, a bode plot of the system`s magnitude response can be obtained.

  1.11 G(s)= (Ω_m (s))/(V_m (s))=K/(τs+1)

Substituting s = jω the magnitude of the frequency response at a frequency ω of the motor input voltage is then defined as

  1.12 |G(s)|=|(Ω_m (jω))/(V_m (jω))|=|K/(τjω+1)|= K/(√(τ^2 ω^2 +1))

The system’s steady state (or low frequency) gain can then be obtained by setting ω = 0, applying a constant signal:

  1.13 K=|G(0)|

The phase shift of the system φ_d can be calculated as:

  1.14 φ_d =φ_(num) -φ_(den)

When φ_(num) and φ_(den) represent the phase angle / delay of the numerator and denominator of the transfer function respectively.

In addition, it can be observed directly from the input output graphs for the sin signal. The phase shift can be expressed as:

  1.15 φ_d =-(t_2)/(t_1)∙360^(°)

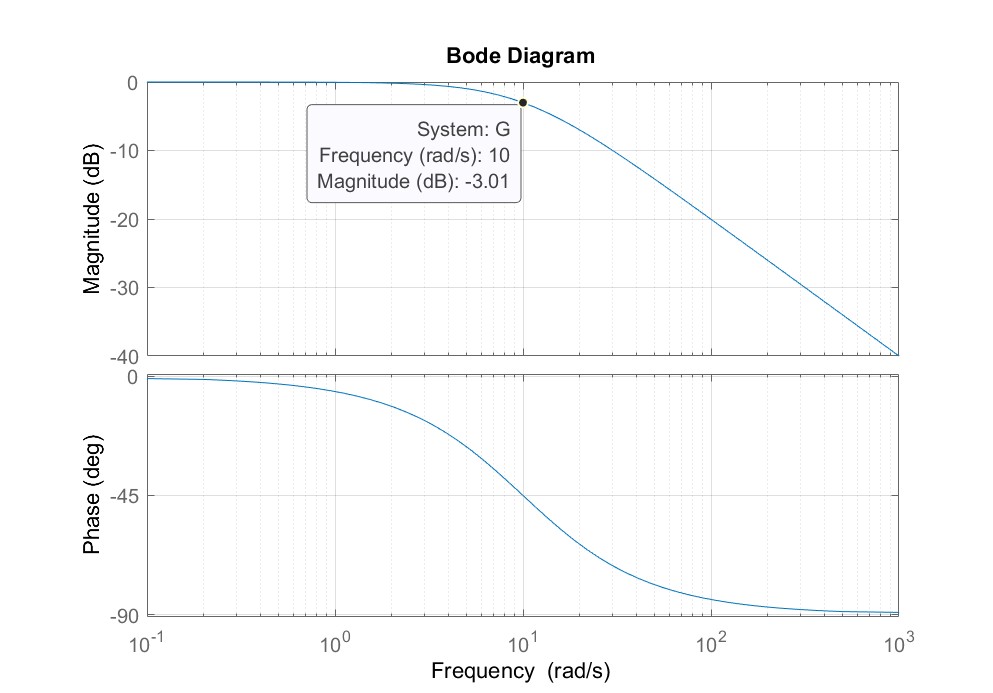
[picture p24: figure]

Figure 4 Bode plot of a first order system with τ=0.1

The Bode plot includes a vital feature known as the cutoff frequency, denoted by ω_b . It's the frequency where the system's gain is 3 dB below its maximum steady-state gain. This 3 dB drop corresponds to the system's half-power point of the system, and defined as 10log_10 0.5 leading to a value of approximately -3.01 dB, or equivalently a magnitude of approximately 1/√2 ≈0.70721≈0.707, or -3.01 dB in terms of the maximum system gain. The cutoff frequency is synonymous with the system's bandwidth and serves as an indicator of the speed at which the system reacts to an input.

## Transient response analysis

In control systems, when a system transitions from one state to another, due to changes in its inputs, it exhibits a certain behavior before settling to its new steady-state. This behavior is termed the transient response. Essentially, it describes how the system reacts to sudden changes, and is a critical aspect to consider, especially when designing systems where rapid and accurate responses are crucial.

Important Parameters in Transient Response:

The performance of control systems during the transient state is often described using the following terms:

- Rise Time (Tr): Time taken for the response to rise from 10% to 90% (or 0% to 100% in some cases) of its final value.
- Peak Time (Tp): Time taken for the response to reach the first peak.
- Overshoot (OS): The amount by which the response exceeds its final steady-state value. It's often expressed as a percentage of the final value.
- Settling Time (Ts): Time taken for the response to stay within a certain percentage (commonly 2% or 5%) of its final value.
- Steady-State Error (Ess): The difference between the desired output and the actual output after the system has settled.

The following figure shows the step response of the system G(s)=0.9/(s^2 +1.4s+1) , and marks all the relevant parameters.

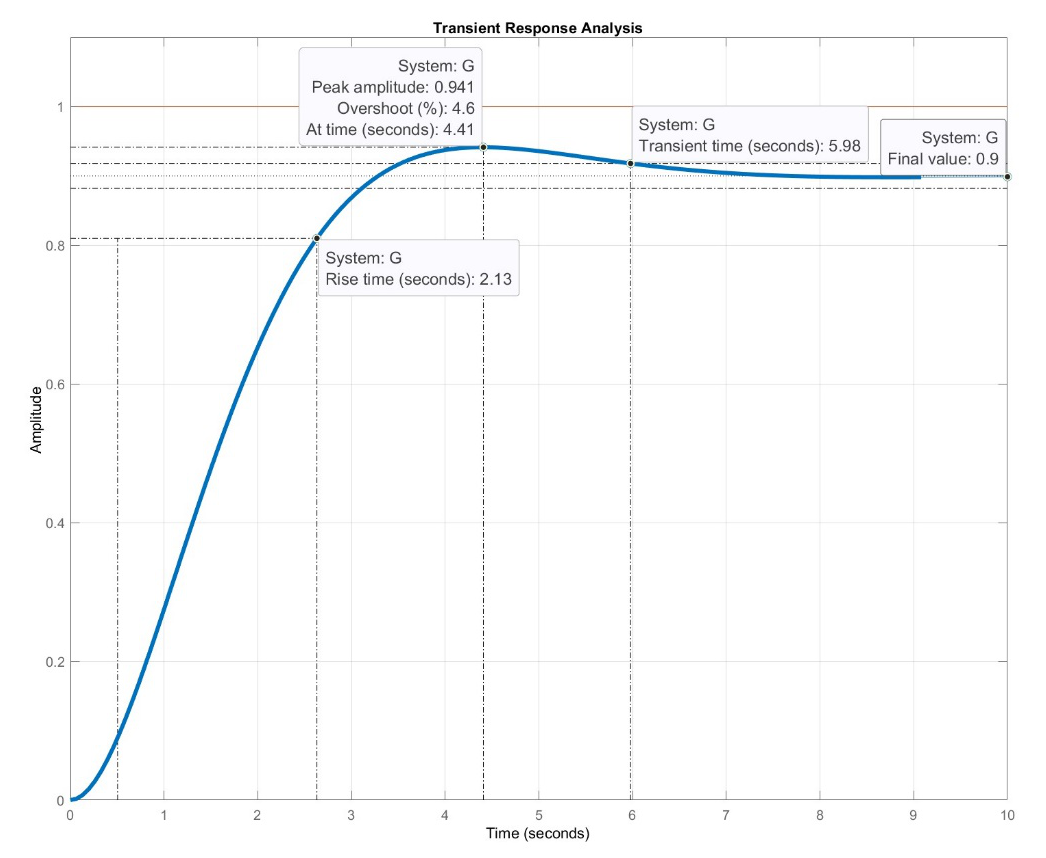
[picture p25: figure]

Figure 5 step response of a second order system

## PID controller

The PID controller, which stands for Proportional-Integral-Derivative, is one of the most widely used feedback control algorithms in industry. Its popularity stems from its effectiveness in a broad range of applications and its relatively straightforward tuning process.

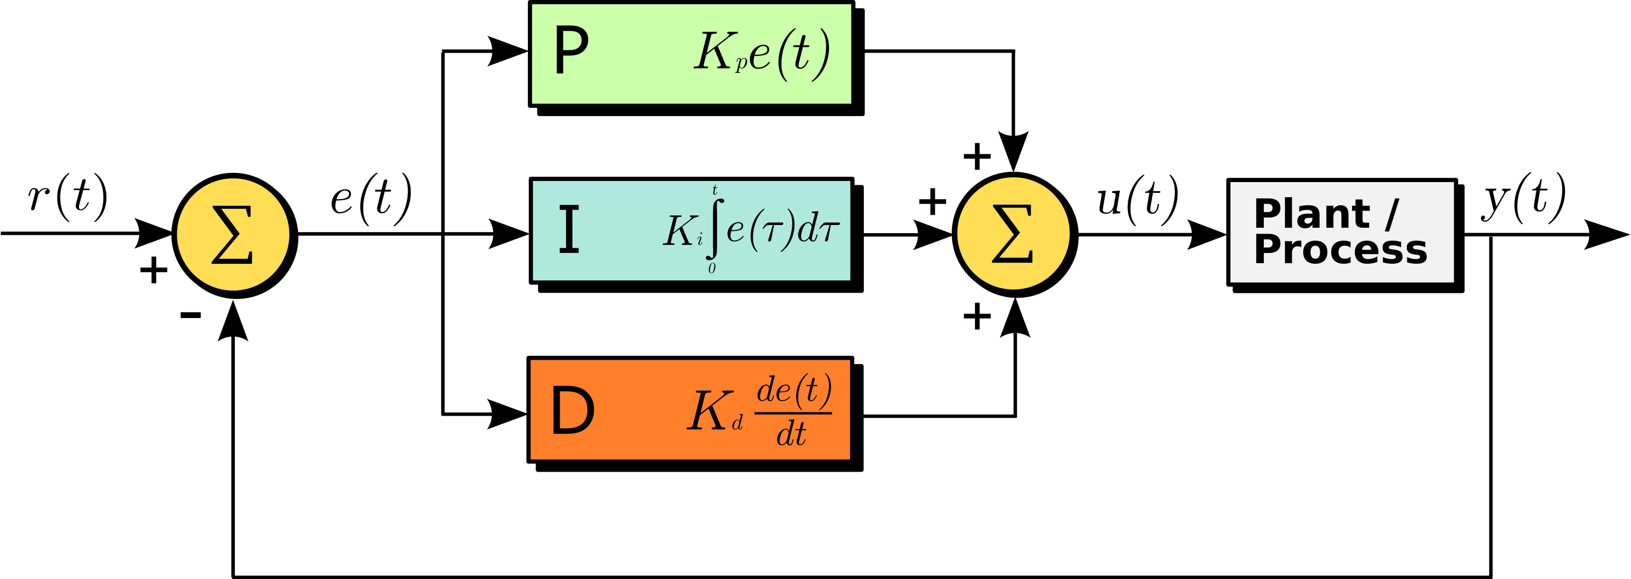
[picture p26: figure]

Figure 6 Block diagram of a PID controller

  1.16 u(t)=K_p e(t)+K_i ∫ e(t)dt+K_d (de(t))/(dt)

The PID controller consists of three main components:

Proportional (P): This part produces a control action that's directly proportional to the error between the setpoint and the measured process variable. The proportional gain Kp determines how aggressively the controller responds to an error.

Integral (I): The integral term is concerned with the accumulated error over time. If there is a persistent, steady-state error, the integral action will build up and eliminate it.

Derivative (D): The derivative action provides a control effort to counteract the rate of error change. It anticipates the future error by its rate of change and provides control action to prevent it from occurring.

For additional reading consider the following links:

Introduction: PID Controller Design https://ctms.engin.umich.edu/CTMS/index.php?example=Introduction&section=ControlPID

## 1.1.1. Proportional speed control

In proportional control, the control action is directly proportional to the error between the desired set point and the actual measured value, in this case, the motor speed. The equation for the control action is given by: u(t)=K_p e(t)=K_p (r(t)-y(t)) ,

K_p is the proportional gain. r(t) = ω_d (t) is the desired angular velocity, y(t)=ω_m (t) is the measured angular velocity and u(t)=v_m (t) is the control impute (the voltage applied to the motor).

The close loop transfer function can be derived

  1.17 T(s)= (Y(s))/(R(s))=(P(s)∙C(s))/(1+P(s)∙C(s))=(K∙K_p)/(τs+1+K∙K_p)

Whereas P(s) is the first order approximation of the dc motor. And C(s)=K_p represent the controller transfer function.

## 1.1.1. Final value theorem

The Final Value Theorem states that if a system is stable and if the limit exists, the steady-state value of a time-domain function f(t) can be found directly from its Laplace Transform F(s) . The theorem is given by:

  1.18 limt→∞f(t)=lims→0s∙F(s)

## 1.1.2. Steady state error

Steady-state error is the difference between the desired and actual velocity of the DC motor once the transients have died down, and the system has reached its steady-state condition. The main reason for this steady-state error in proportional control lies in the nature of the control law itself. Since the control action is proportional to the error, when the error reduces to zero, so does the control input. In physical systems like a DC motor, there may be disturbances, such as friction, that require continuous control effort to overcome. If the control input becomes zero, these disturbances may cause the system to drift away from the desired set point.

Given a step input R(s)=1/s The error transfer function can be derived as:

  1.19 E(s)=R(s)-Y(s)= R(s)-T(s)∙R(s)=1/s-(K∙K_p)/(s(τs+1+K∙K_p ))

By applying the final value theorem:

  1.20 limt→∞e(t)=lims→0s∙E(s)=lims→0s(1/s-(K∙K_p)/(s(τs+1+K∙K_p )))=1-(K∙K_p)/(1+K∙K_p)

The steady state error is given by:

  1.21 e_(ss) =1-(K∙K_p)/(1+K∙K_p)

# 2. Pre Lab

## Step response modeling

a. Given the first order approximation of a dc motor, what would be the values of K and τ (give parametric solution).
b. Using Matlab, plot the step response of the following first order system G(s)=1/(0.1s+1) Mark the time constant τ and the steady state gain K.

## Frequency response modeling

a. Using Matlab plot the response of the system G(s)=1/(0.1s+1) to various sin inputs (at list 5 different frequencies), calculate the gain change as a function of frequency from the sin responses. You can use the "lsim” function in Matlab to simulate a system response to an arbitrary input signal in the time domain. Or implement it in Simulink.
b. Approximate the cutoff frequency ω_b and plot the system`s sinusoidal response at this frequency.
c. Using the first order approximation G(s)=K/(τs+1) and by evaluating the magnitude of the transfer function at the cutoff frequency ω_b , derive an expression to determine τ based on ω_b

Hint: |G(ω_b )|=1/(√2)|G(0)|

d. Using the first order approximation G(s)=K/(τs+1) and by evaluating the phase of the transfer function, derive an expression to determine τ in terms of the frequency input of the signal and the resulting phase delay.

Hint: φ_d =Phase(K/(τs+1))|_(s=jω)

## PID controller

a. Calculate the parametric steady state error for the given system G(s)=1/(0.1s+1) in a close loop using a proportional gain controller Kp and a step response input.
b. Plot the response of the close loop system using Kp=10, compare the steady state value to the theoretical.
c. Calculate the transfer function of a closed loop velocity controlled dc motor with a PI Controller using the first order approximation for the dc motor transfer function.
d. Calculate the steady state error for the above.
e. For the given system: G(s)=1/(0.1s+1) Design a PI controller (using any method) with rise time 0.2s>T_r >0.1s , overshoot of up to 15% and settling time of up to 0.5s.
f. Consider the DC motor equations, what will happen to the time constant τ in case an additional rotating mass will be added to the motor. Hint: consider what will happen to the inertia J.

# 3. In Lab

## Introduction

Welcome to the lab! Before we dive into the experiments, it's crucial to familiarize yourself with the hardware we'll be working with. The setup you will be working with is called HexaMotor. It includes a DC motor with an encoder connected to an Arduino MKR motor controller. This can be controlled using Matlab Simulink. Additional information is available in the appendix of this manual.

- Start by opening Matlab R2022b
- Navigate to …\Documents\MATLAB
- Create a new folder with your name and copy the lab materials into it
- Open “HexaMotor_MotorTest_V02.slx” Simulink model.
- Prior to running the model make sure the setup is connected to the PC through USB cable and the power supply is connected to the socket.
- Press the On/Off Button at the back and make sure the light is on.
- Make sure the rotating mass is present.
- Under hardware you will find the Monitor&Tune button, press it, if everything is properly set it will compile the Simulink model and upload a C++ code to the micro controller. When the process has finished the button with be switch to a stop button and at the button bar a simulation time will start counting.

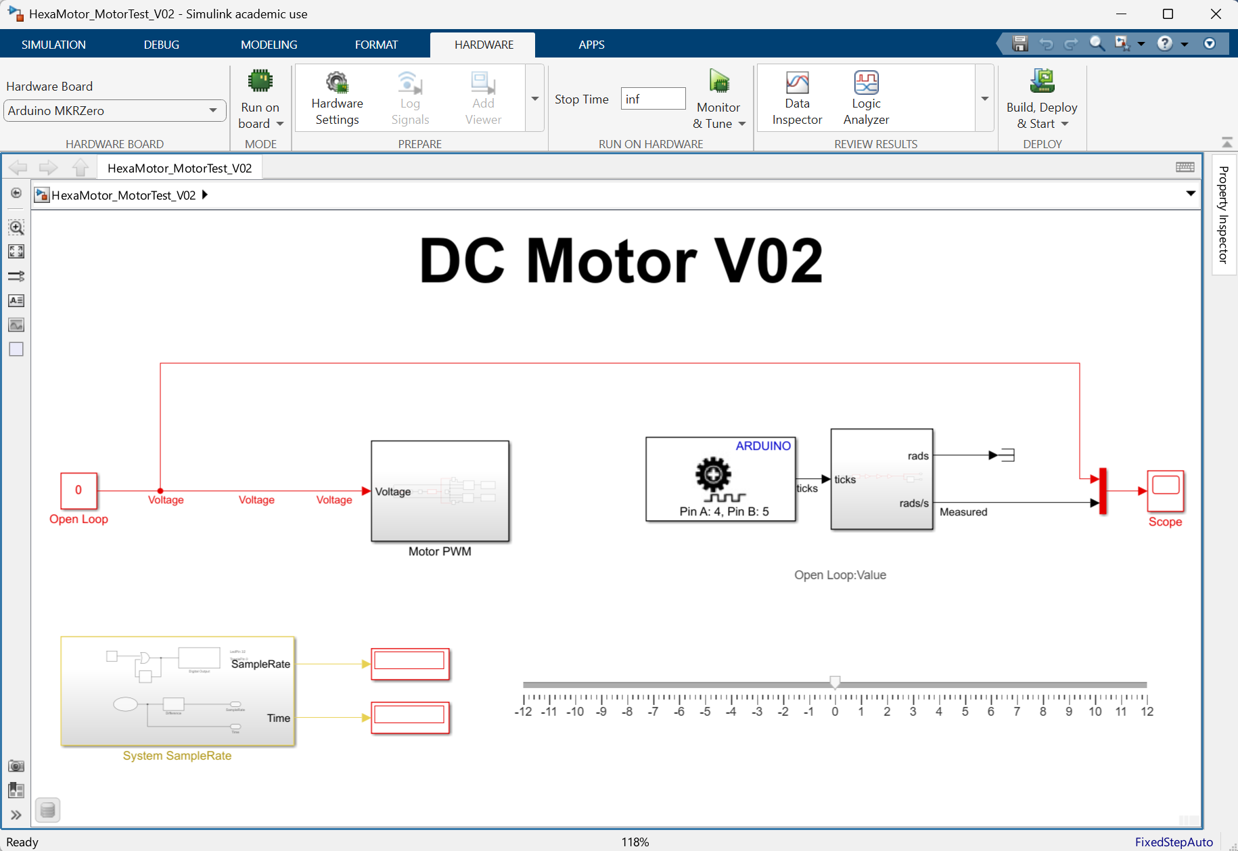
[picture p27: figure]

Figure 7 Simulink model for interaction with the HexaMotor Setup

The Simulink model acts as an interface, allowing the interaction with the hardware and monitoring it`s signals.

- Double click on the scope, it will open the signals from the system. The angular velocity measured from the motor`s encoder. And the applied voltage to the motor.
- Change the open loop voltage, either by writing the open loop block values between [-12 ..12] or using the slide bar.

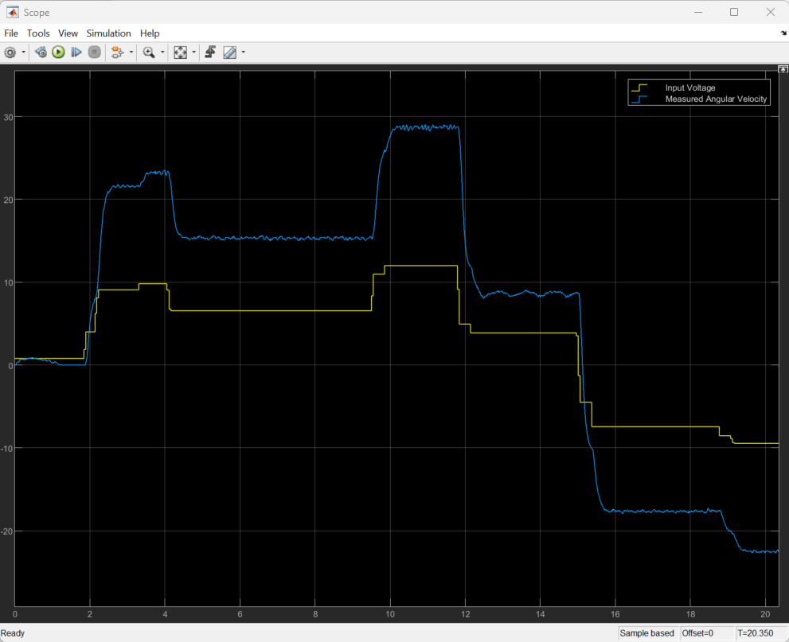
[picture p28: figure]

Figure 8 Live scope data from motor response

- On the button left you will notice a block named System SampleRate, the block outputs the simulation sample time and the measured time, and in additional performs I/O toggling which can be check with external hardware to verify the actual Sample Rate of the system.
- And at the top you near the Stop / Monitor & Tune button there is Stop Time, which can be change from inf to any number and will stop the simulation.
- You can export the scope to a figure by pressing File→Print To Figure, in the figure it is possible to make measurements by selecting Tools→Data Tips and clicking the plot. If you press Shift while selecting a data point it will add an additional data point. Then the data points can be moved around. Explore the figure and scope options and save a plot for the report. A good plot contains Title, Lables, Legend, units.

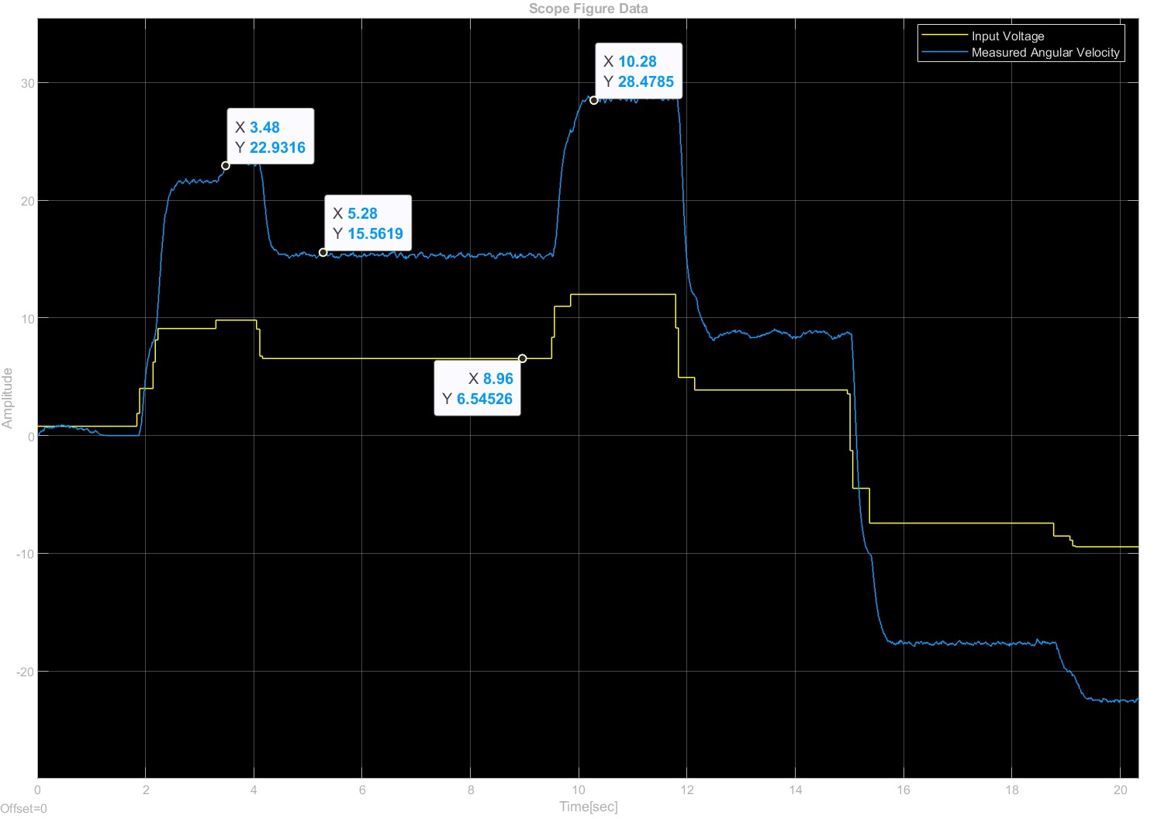
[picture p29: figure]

Figure 9 Generated figure from the live scope

- In addition, the scope data is exported to the Matlab environment under the structure variable ScopeData when the simulation is stopped. You can access the data using the following commands:

input = ScopeData.time;

input = ScopeData.signals.values(:,1);

output = ScopeData.signals.values(:,2);

Or plot it directly using:

plot(ScopeData.time,ScopeData.signals.values)

- In addition, it is possible to save the data for later processing by writing:

save record_name ScopeData

And retrieving it back to Matlab either by double clicking the saved file or writing:

load('record_name.mat')

Note that you may notice some oscillation at constant voltage, that is due to non-linearity of the friction. If you measure the phenomena you may notice that its frequency is the same as the rotation angle frequency.

For the Report:

a. Present a plot using a figure from the scope simulation
b. Include a plot generated in the Matlab environment, using the ScopeData variable. Don’t forget to include legend, Title, Lables and Grid to the plot. You can check how to add this by typing “help plot” in the Matlab environment.
c. Write the max velocity of the motor (at 12V, -12V)

## Coulomb friction

We will begin our analysis by identifying the Coulomb friction within the system. Coulomb friction, often referred to as 'dry friction,' is a constant magnitude friction that opposes motion and is independent of the relative velocity between surfaces. In the context of a brushed DC motor, this phenomenon manifests as the Dead-Zone. The Dead-Zone is a region in which the motor doesn’t produce any movement even though a voltage is applied. This is primarily because the applied voltage or torque is not sufficient to overcome the inherent static friction of the system. It's crucial to identify and compensate for this Dead-Zone to ensure smooth operation and accurate control of the motor, particularly during its startup and low-speed operations

- Using the same “HexaMotor_MotorTest_V02.slx” Simulink model. Find the minimum voltage values required to start the motor motion. You can change the slider range if you wish to use it to find the minimal values.

You can push the motor a bit with your hand and try to find the least resistance angle. (due to the non-linearity in the friction mentioned earlier).

- Write those values for next section.

## Step response modeling

In this section we will use the bump test to estimate the system`s transfer function. We will use in two methods, one with initial voltage 0, and the other with initial voltage of 2 volts.

- Open the “HexaMotor_System_Identification_V02.slx” Simulink model. Make sure the switch is set to step input.
- Update the Motor Friction Preamp gains with the values found in the previous section.
- Adjust the step values to step at 1 second, from initial 0-volt to 7-volt step, update the Stop time to 5 seconds and record the response.
- Run the experiment again this time with a step from initial 2-volt to 9-volt step. Record the response.

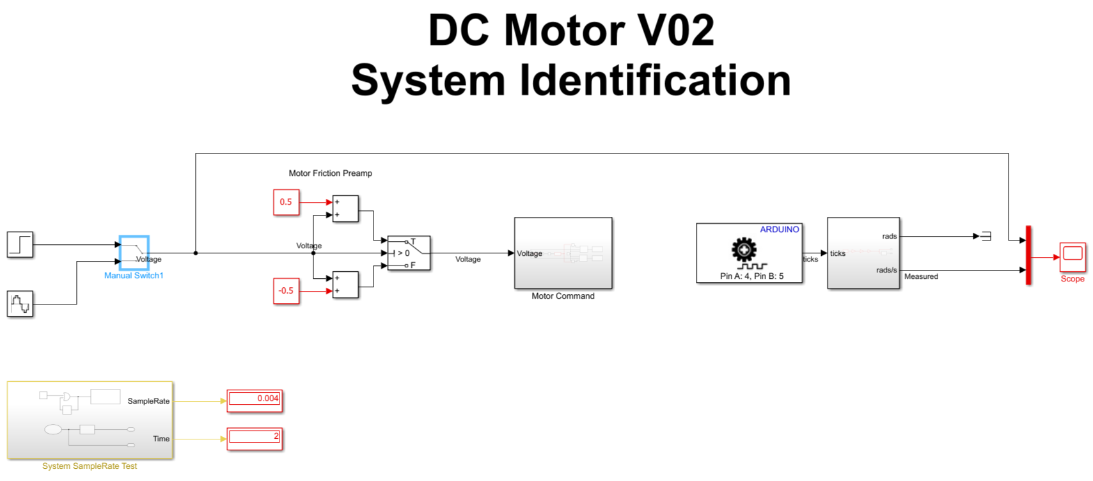
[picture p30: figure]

Figure 10 Simulink model : HexaMotor_System_Identification_V02.slx”

For the Report:

a. Find the transfer function from both experiments recording using the first order approximation. If the difference is more than 10% check your calculations. Remember that the step size is 7 volts. And in the second experiment the initial angular velocity isn`t zero. Consider in which cases it is preferred to perform one or the other.
b. Create a plot in Matlab which contains a step response from 0 volts to 7 volts from the recordings and as a simulation using the step function in Matlab for the identified transfer function.

Hint: Use the following commands to simulate a step response similar to the experiment. Don’t forget to include title. Legend etc. to the plot.

% T Is the calculated transfer function

plot(ScopeData.time,ScopeData.signals.values)

hold on

plot(ScopeData.time+1,step(T,ScopeData.time)*7)

## Frequency response modeling

In this section we will generate a bode plot for the system and derive the transfer function using its frequency response to several input frequencies.

- Using the same “HexaMotor_System_Identification_V02.slx” Simulink model. Move the switch to a sin input. And update the stop time to inf.
- Update the parameters of the input Amplitude:7 Frequency (rad/sec): 1 rad/sec and run the model, notice the system response.
- Measure the time delay and magnitude of the response.


Figure 11 Sine wave response - Live scope

For the Report:

a. Fill up the following table make sure to record at list 7 frequencies at the range of [0..30] rad/sec

Hint: you can change the frequencies while the model is running and print to figure while it runs. Gain=(Max velocity)/(Input Amplitude) , ω=0 can be calculated from the step response.

Frequency (Rad/sec) | Input Amplitude (V) | Max velocity (rad/s) | Time Delay (s) | Gain (rad/s/v) | Gain(dB). | Phase (degree)
0
…..
30

b. Approximate the ω_b by evaluating the frequency at which the amplitude |G(ω_b )|=1/(√2)|G(0)| . store the response for that frequency and calculate the time constant τ . How close it is to the τ calculated from the step response? Which method will give a more precise result?

Hint: Pre lab question 2.2 c.

c. Plot a bode plot using the data from the table.

Hint: use the following Matlab commands:

% Create a frequency response data object

% units: amplitudes [rad/s/v], frequencies [Rad/sec], phases [Deg].

freq_data = idfrd(amplitudes, frequencies, 0);

% Estimate transfer function (first order system)

sys = tfest(freq_data, 1)

% plot bode like plot, with the added points

s=tf('s');

w = logspace(-1,2,100);

% sys∙1/(0.05s+1) - sets a second order system with a low pass filter at τ=0.05 , but a more proper % method would be to estimate sys as a second order system with a known pole of the filter

[mag,phase] = bode(sys*(1/(0.05*s+1)),w);

figure(1);

subplot(2,1,1)

semilogx(w,20*log10(squeeze(mag)))

hold on

semilogx(frequencies, 20*log10(amplitudes), '*');

subplot(2,1,2)

semilogx(w,squeeze(phase))

hold on

semilogx(frequencies,phases)

Example Plot


Figure 12 Bode plot containing simulated and measured data

Note: The resulting plot contains a phase up to -180 degrees due to the presence of a low pass filter for the velocity measurements at τ=0.05

d. How close the transfer function derived from the bode estimation to the one found from the step response. What do you think, which one is more precise? which was faster to achieve?

## PID controller

In velocity control setups for motors, a PI (Proportional-Integral) controller is commonly used. While the PID controller includes all three terms — Proportional, Integral, and Derivative — the PI controller only uses the Proportional and Integral terms. The reason for excluding the Derivative term in velocity control is due to the nature of the application. In many motor control scenarios, the Derivative term can introduce noise or lead to excessive sensitivity to rapid changes. Given the objectives of velocity control, the PI controller strikes a balance between performance and stability, delivering smooth and consistent motor speed without the potential drawbacks of the Derivative term.

## 3.1.1. Steady state error

We will start by measuring the steady-state error of the angular velocity using a simple proportional gain of 1 and comparing the results to a simulated system based on the model identified in previous sections.

- Open the “HexaMotor_Velocity_Control_V02.slx” Simulink model.
- Update the Motor Friction Preamp gains with the values found in the first section.
- Adjust the square wave Pulse Generator a period of 4 seconds pulse width of 2 seconds and delay of 1 second, set the amplitude to 15 rad/s and update the Stop time of the simulation to 7 seconds.
- Update the PI controller to proportional gain Kp=1 and integral gain Ki=0
- Run the experiment.

Figure 13 Simulink model : HexaMotor_Velocity_Control_V02.slx


For the Report:

a. Compare the steady state error to the theoretical one
b. Using the recording of the experiments create a plot in Matlab containing the response from the experiment and simulated results from the plant found in section 3.4. You may notice that the responses aren`t exactly the same, that is due to non-linearity’s in the actual setup and to the presence of the low pass filter for the velocity measurement. You may also add simulated results including the low pass filter for comparison. ( LPF(s)=1/(0.05s+1) ).

Hint: use the following Matlab commands: (do not forget to update the transfer function and add grid, axis labels, title to the plot).

% Generate plots from recordings and simulated transfer function

s=tf('s');

G = 2.5/(0.1*s+1); % update the estimated transfer function

LPF = 1/(0.05*s+1);

figure(1)

plot(ScopeData.time,ScopeData.signals.values(:,1))

hold on

plot(ScopeData.time,ScopeData.signals.values(:,2),'.');

[y,t] = lsim(G/(1+G),ScopeData.signals.values(:,1),ScopeData.time);

plot(t,y);

[y,t] = lsim(G*LPF/(1+G*LPF),ScopeData.signals.values(:,1),ScopeData.time);

plot(t,y);


Figure 14 Square wave response, actual system and simulated models

## 3.1.2. PI Controller manual tuning

In this section, we will discuss how to tune the parameters of a PI (Proportional-Integral) controller to achieve a desired response.

- Begin by setting the integral gain to 0 and adjust the proportional gain within the range of [0 to 2] until the response exhibits a slight overshoot or reaches the desired rise time.
- Introduce the integral gain to minimize the steady-state error and ensure the response meets the desired peak time, overshoot, and settling requirements. If needed, decrease the proportional gain.
- Fine-tune both the Proportional and Integral gains as required to fulfill the design specifications.

Adjust the parameter to get the following control specifications:

0.3s>T_(PeakTime) >0.15s , T_(Settling) <0.5s , Overshoot<15%

Hint: you can set the Stop time of the simulation to ‘inf’ while tunning the parameters.

For the Report:

a. Plot the response of the system, with the simulated theoretical model. Mark the important criteria and calculate overshoot of the system.


Figure 15 Square wave response, actual system and simulated models

Note: The resulting simulated plot differs slightly from the actual response. This difference arises because the simulation does not account for all the non-linearities of the actual setup. Additionally, we approximated the system as a first-order system, but ideally, it should have been estimated as a second-order system due to the presence of the low-pass filter, whose pole is not significantly distant from the motor's pole.

Don't forget to turn off the system at the end of the experiment using the switch cable

# 4. Appendix

Github Page: https://github.com/TALs-Education/HexaMotor

## DC Motor

This gearmotor consists of a low-power, 12 V brushed DC motor combined with a 20.4:1 metal spur gearbox, and it has an integrated 48 CPR quadrature encoder on the motor shaft, which provides 979.62 counts per revolution of the gearbox’s output shaft.

Product page: https://www.pololu.com/product/4883

Data Sheet: https://www.pololu.com/file/0J1829/pololu-25d-metal-gearmotors.pdf

## Arduino board / Motor Driver

The MKR Zero board is used with a motor driver to drive the motor and read the encoders.

MKR Zero: https://docs.arduino.cc/hardware/mkr-zero

MP6550 Brushed DC Motor Driver: https://www.pololu.com/product/4733

## Simulink Support package

With MATLAB and Simulink Support Packages for Arduino® hardware, you can use MATLAB and Simulink to interactively communicate with your Arduino. Simulink also enables you to perform model deployment for standalone operations on Arduino boards.

MathWorks: https://www.mathworks.com/hardware-support/arduino.html

## 3D Model – Fusion360

The setup is design in Fusion360 as an open source project, for educational purposes. Available at:

Fusion360: https://a360.co/4fCxmAJ

The Iby and Aladar Fleischman Faculty of Engineering Tel Aviv University

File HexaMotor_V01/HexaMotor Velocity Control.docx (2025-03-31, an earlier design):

# Velocity Control


# HexaMotor

Experiment objectives:

• Introduction to DC motor dynamic equations.

• Coulomb Friction identification and handling

• System identification using open loop step response, model validation.

• System identification using frequency response, model validation.

• Velocity control implementation. Proportional, Proportional - Integral control loops.

• Controller performance under load.

# 1. Introduction

DC motors are electromechanical devices that convert electrical energy into mechanical energy, using principles of electromagnetism. They are known for their simple construction, high reliability, and ease of control. These features make them suitable for various applications, from small electronic devices to large industrial machinery.

## DC motor equations

The electric equivalent circuit of the armature and the free-body diagram of the rotor are shown in Figure 1.


Figure 1: Electric equivalent circuit of a dc motor

V - Applied Voltage: The voltage applied across the motor's terminals. It is the input to the system and determines the driving force behind the motor.

i - Armature Current: The current flowing through the armature winding, responsible for creating the magnetic field that drives the motor.

R - Armature Resistance: The resistance of the armature winding, which opposes the flow of current.

L - Armature Inductance: The inductance of the armature winding, which determines how quickly the current can change in the coil.

V_(emf) - Back Electromotive Force (EMF): Voltage generated by the motor's rotation, opposing the applied voltage.

K_T - Torque Constant: A factor that relates the motor's torque output to its current. It depends on the motor's construction.

K_b - Back EMF Constant: A factor that relates the motor's back EMF to the angular velocity. It often equals the torque constant in many DC motors.

T - Torque: The twisting force exerted by the motor on its shaft.

T_(friction) - Friction Torque: The torque opposing the motor's rotation due to various frictional effects.

J - Moment of Inertia: A measure of the motor's resistance to changes in its rotational speed. It depends on the distribution of mass in the rotating parts.

ω - Angular Velocity: The rate of rotation of the motor's shaft, often the controlled output in velocity control systems.

B - Damping Coefficient: A parameter representing the viscous friction in the system. It characterizes how the frictional forces are proportional to the angular velocity.

T_(coulomb) - Coulomb friction.

s - Complex Frequency (Laplace Variable): In the context of the transfer function, s is a complex variable used in the Laplace transform.

Voltage Equation:

  1.1 V=Ri+L(di)/(dt)+K_b ω

where V is the applied voltage, R is the armature resistance, i is the armature current, L is the armature inductance, K_b is the back EMF constant, and ω is the angular velocity.

Torque Equation:

  1.2 T=K_T i-T_(friction) - J(dω)/(dt)

where T is the torque, K_T is the torque constant, T_(friction) is the friction torque, J is the moment of inertia, and (dω)/(dt) is the angular acceleration.

Friction Model:

  1.3 T_(friction) =Bω+T_(coulomb)

By substituting the expressions for torque and friction into the torque equation and solving for the differential equation relating the applied voltage to the angular velocity, we obtain:

  1.4 LJ(d^2 ω)/(dt^2)+(RJ+BL)(dω)/(dt)+(BR+K_T K_b )ω=K_T V

Now, the transfer function relating the applied voltage V(s) to the angular velocity Ω(s) in the Laplace domain (assuming zero initial conditions) is:

  1.5 G(s)=(K_T)/(LJs^2 +(Rj+BL)s+(BR+K_T K_b ))

## First order approximation:

Armature Inductance (L): The inductive term L(di)/(dt) in the voltage equation is often neglected. This is under the assumption that the armature inductance is small compared to the resistance, meaning that the electrical dynamics are much faster than the mechanical dynamics.

First-Order Transfer Function:

  1.6 G(s)=(K_T)/((RJ)s+(BR+K_T K_b ))

This first-order model offers a simpler representation of the DC motor's dynamics and is useful for preliminary control design or when the details of the electrical subsystem are not critical. It captures the main characteristics of the motor's velocity response but omits some of the subtler dynamics present in the full second-order model.

For additional reading consider the following links:

DC motor velocity model:

https://ctms.engin.umich.edu/CTMS/index.php?example=MotorSpeed&section=SystemModeling

System analysis:

https://ctms.engin.umich.edu/CTMS/index.php?example=MotorSpeed&section=SystemAnalysis

## Coulomb friction

Coulomb friction is distinctive from viscous damping, as it remains constant regardless of the speed of the motor. It contributes to non-linearity in the system and can lead to challenges in maintaining precise control, especially at low speeds.

Measuring Coulomb friction in a DC motor is essential for designing effective control strategies. One common method to identify this friction involves applying a small, controlled voltage to the motor and observing the threshold voltage at which the motor begins to rotate. By relating this threshold voltage to the known torque-to-current relationship, the Coulomb friction torque can be quantified.

## Step response modeling

Step response modeling, commonly referred to as the "bump test," is a straightforward examination grounded in the step response characteristics of a stable system. In this test, a step input is applied to the system, and the subsequent response is observed and recorded. To illustrate this concept, imagine a system defined by a particular transfer function:

  1.7 G(s)=K/(τs+1)

The step response in the shown figure is generated using K=10 rad/V and τ=0.1s .


Figure 2 Step response of eq1.7 with K=10, τ=0.05s.

The time constant τ is a measure of how fast the system responds to a change in input. It's defined as the time it takes for the system's response to reach approximately 63.2% of its final value (steady-state value) after a step change in input.

To see why it is the case lets evaluate a first-order linear system that has the general form of a time constant τ and can be described by the following first-order differential equation:

  1.8 τ(dy(t))/(dt)+y(t)=Ku(t)

If the system is subjected to a step input of magnitude A, the response y(t) can be described by:

  1.9 y(t)=KA(1-e^(-t/τ) )

By evaluation the response at t=τ we get:

  1.10 y(τ)=KA(1-e^(-τ/τ) )≈KA∙0.632

## Frequency response modeling

System analysis with a sinusoidal input provides insights into the motor's frequency response, resonance behavior, and the effect of damping. The motor's transfer function can be used to investigate how different frequencies of the sinusoidal input are amplified or attenuated, revealing information about the stability, bandwidth, and transient response of the system.

When a sine wave is used as an input for a DC motor, the motor's output results in a sinusoid of the same frequency but is scaled and delayed as by the frequency response theorem. As illustrated in Figure 3, the length of one full period of the sinusoid is represented by t1, while t2 indicates the time delay between the input voltage signal Vm, and the corresponding scaled output speed signal, ω_m .


Figure 3 System response with a sinusoidal signal

The magnitude response of the resulting output changes with respect to the frequency of the applied sinusoid and can be used to find the time constant τ of the DC motor with the first order approximation. In addition, a bode plot of the system`s magnitude response can be obtained.

  1.11 G(s)= (Ω_m (s))/(V_m (s))=K/(τs+1)

Substituting s = jω the magnitude of the frequency response at a frequency ω of the motor input voltage is then defined as

  1.12 |G(s)|=|(Ω_m (jω))/(V_m (jω))|=|K/(τjω+1)|= K/(√(τ^2 ω^2 +1))

The system’s steady state (or low frequency) gain can then be obtained by setting ω = 0, applying a constant signal:

  1.13 K=|G(0)|

The phase shift of the system φ_d can be calculated as:

  1.14 φ_d =φ_(num) -φ_(den)

When φ_(num) and φ_(den) represent the phase angle / delay of the numerator and denominator of the transfer function respectively.

In addition, it can be observed directly from the input output graphs for the sin signal. The phase shift can be expressed as:

  1.15 φ_d =-(t_2)/(t_1)∙360^(°)


Figure 4 Bode plot of a first order system with τ=0.1

The Bode plot includes a vital feature known as the cutoff frequency, denoted by ω_b . It's the frequency where the system's gain is 3 dB below its maximum steady-state gain. This 3 dB drop corresponds to the system's half-power point of the system, and defined as 10log_10 0.5 leading to a value of approximately -3.01 dB, or equivalently a magnitude of approximately 1/√2 ≈0.70721≈0.707, or -3.01 dB in terms of the maximum system gain. The cutoff frequency is synonymous with the system's bandwidth and serves as an indicator of the speed at which the system reacts to an input.

## Transient response analysis

In control systems, when a system transitions from one state to another, due to changes in its inputs, it exhibits a certain behavior before settling to its new steady-state. This behavior is termed the transient response. Essentially, it describes how the system reacts to sudden changes, and is a critical aspect to consider, especially when designing systems where rapid and accurate responses are crucial.

Important Parameters in Transient Response:

The performance of control systems during the transient state is often described using the following terms:

- Rise Time (Tr): Time taken for the response to rise from 10% to 90% (or 0% to 100% in some cases) of its final value.
- Peak Time (Tp): Time taken for the response to reach the first peak.
- Overshoot (OS): The amount by which the response exceeds its final steady-state value. It's often expressed as a percentage of the final value.
- Settling Time (Ts): Time taken for the response to stay within a certain percentage (commonly 2% or 5%) of its final value.
- Steady-State Error (Ess): The difference between the desired output and the actual output after the system has settled.

The following figure shows the step response of the system G(s)=0.9/(s^2 +1.4s+1) , and marks all the relevant parameters.


Figure 5 step response of a second order system

## PID controller

The PID controller, which stands for Proportional-Integral-Derivative, is one of the most widely used feedback control algorithms in industry. Its popularity stems from its effectiveness in a broad range of applications and its relatively straightforward tuning process.


Figure 6 Block diagram of a PID controller

  1.16 u(t)=K_p e(t)+K_i ∫ e(t)dt+K_d (de(t))/(dt)

The PID controller consists of three main components:

Proportional (P): This part produces a control action that's directly proportional to the error between the setpoint and the measured process variable. The proportional gain Kp determines how aggressively the controller responds to an error.

Integral (I): The integral term is concerned with the accumulated error over time. If there is a persistent, steady-state error, the integral action will build up and eliminate it.

Derivative (D): The derivative action provides a control effort to counteract the rate of error change. It anticipates the future error by its rate of change and provides control action to prevent it from occurring.

For additional reading consider the following links:

Introduction: PID Controller Design https://ctms.engin.umich.edu/CTMS/index.php?example=Introduction&section=ControlPID

## 1.1.1. Proportional speed control

In proportional control, the control action is directly proportional to the error between the desired set point and the actual measured value, in this case, the motor speed. The equation for the control action is given by: u(t)=K_p e(t)=K_p (r(t)-y(t)) ,

K_p is the proportional gain. r(t) = ω_d (t) is the desired angular velocity, y(t)=ω_m (t) is the measured angular velocity and u(t)=v_m (t) is the control impute (the voltage applied to the motor).

The close loop transfer function can be derived

  1.17 T(s)= (Y(s))/(R(s))=(P(s)∙C(s))/(1+P(s)∙C(s))=(K∙K_p)/(τs+1+K∙K_p)

Whereas P(s) is the first order approximation of the dc motor. And C(s)=K_p represent the controller transfer function.

## 1.1.1. Final value theorem

The Final Value Theorem states that if a system is stable and if the limit exists, the steady-state value of a time-domain function f(t) can be found directly from its Laplace Transform F(s) . The theorem is given by:

  1.18 limt→∞f(t)=lims→0s∙F(s)

## 1.1.2. Steady state error

Steady-state error is the difference between the desired and actual velocity of the DC motor once the transients have died down, and the system has reached its steady-state condition. The main reason for this steady-state error in proportional control lies in the nature of the control law itself. Since the control action is proportional to the error, when the error reduces to zero, so does the control input. In physical systems like a DC motor, there may be disturbances, such as friction, that require continuous control effort to overcome. If the control input becomes zero, these disturbances may cause the system to drift away from the desired set point.

Given a step input R(s)=1/s The error transfer function can be derived as:

  1.19 E(s)=R(s)-Y(s)= R(s)-T(s)∙R(s)=1/s-(K∙K_p)/(s(τs+1+K∙K_p ))

By applying the final value theorem:

  1.20 limt→∞e(t)=lims→0s∙E(s)=lims→0s(1/s-(K∙K_p)/(s(τs+1+K∙K_p )))=1-(K∙K_p)/(1+K∙K_p)

The steady state error is given by:

  1.21 e_(ss) =1-(K∙K_p)/(1+K∙K_p)

# 2. Pre Lab

## Step response modeling

a. Given the first order approximation of a dc motor, what would be the values of K and τ (give parametric solution).
b. Using Matlab, plot the step response of the following first order system G(s)=1/(0.1s+1) Mark the time constant τ and the steady state gain K.

## Frequency response modeling

a. Using Matlab plot the response of the system G(s)=1/(0.1s+1) to various sin inputs (at list 5 different frequencies), calculate the gain change as a function of frequency from the sin responses. You can use the "lsim” function in Matlab to simulate a system response to an arbitrary input signal in the time domain. Or implement it in Simulink.
b. Approximate the cutoff frequency ω_b and plot the system`s sinusoidal response at this frequency.
c. Using the first order approximation G(s)=K/(τs+1) and by evaluating the magnitude of the transfer function at the cutoff frequency ω_b , derive an expression to determine τ based on ω_b

Hint: |G(ω_b )|=1/(√2)|G(0)|

d. Using the first order approximation G(s)=K/(τs+1) and by evaluating the phase of the transfer function, derive an expression to determine τ in terms of the frequency input of the signal and the resulting phase delay.

Hint: φ_d =Phase(K/(τs+1))|_(s=jω)

## PID controller

a. Calculate the parametric steady state error for the given system G(s)=1/(0.1s+1) in a close loop using a proportional gain controller Kp and a step response input.
b. Plot the response of the close loop system using Kp=10, compare the steady state value to the theoretical.
c. Calculate the transfer function of a closed loop velocity controlled dc motor with a PI Controller using the first order approximation for the dc motor transfer function.
d. Calculate the steady state error for the above.
e. For the given system: G(s)=1/(0.1s+1) Design a PI controller (using any method) with rise time 0.2s>T_r >0.1s , overshoot of up to 15% and settling time of up to 0.5s.
f. Consider the DC motor equations, what will happen to the time constant τ in case an additional rotating mass will be added to the motor. Hint: consider what will happen to the inertia J.

# 3. In Lab

## Introduction

Welcome to the lab! Before we dive into the experiments, it's crucial to familiarize yourself with the hardware we'll be working with. The setup you will be working with is called HexaMotor. It includes a DC motor with an encoder connected to an Arduino MKR motor controller. This can be controlled using Matlab Simulink. Additional information is available in the appendix of this manual.

- Start by opening Matlab R2022b
- Navigate to …\Documents\MATLAB
- Create a new folder with your name and copy the lab materials into it
- Open “HexaMotor_MotorTest.slx” Simulink model.
- Prior to running the model make sure the setup is connected to the PC through USB cable and the power supply is connected to the socket.
- Press the On/Off Button at the back and make sure the light is on.
- Make sure the rotating mass is present.
- Under hardware you will find the Monitor&Tune button, press it, if everything is properly set it will compile the Simulink model and upload a C++ code to the micro controller. When the process has finished the button with be switch to a stop button and at the button bar a simulation time will start counting.


Figure 7 Simulink model for interaction with the HexaMotor Setup

The Simulink model acts as an interface, allowing the interaction with the hardware and monitoring it`s signals.

- Double click on the scope, it will open the signals from the system. The angular velocity measured from the motor`s encoder. And the applied voltage to the motor.
- Change the open loop voltage, either by writing the open loop block values between [-12 ..12] or using the slide bar.


Figure 8 Live scope data from motor response

- On the button left you will notice a block named System SampleRate, the block outputs the simulation sample time and the measured time, and in additional performs I/O toggling which can be check with external hardware to verify the actual Sample Rate of the system.
- And at the top you near the Stop / Monitor & Tune button there is Stop Time, which can be change from inf to any number and will stop the simulation.
- You can export the scope to a figure by pressing File→Print To Figure, in the figure it is possible to make measurements by selecting Tools→Data Tips and clicking the plot. If you press Shift while selecting a data point it will add an additional data point. Then the data points can be moved around. Explore the figure and scope options and save a plot for the report. A good plot contains Title, Lables, Legend, units.


Figure 9 Generated figure from the live scope

- In addition, the scope data is exported to the Matlab environment under the structure variable ScopeData when the simulation is stopped. You can access the data using the following commands:

input = ScopeData.time;

input = ScopeData.signals.values(:,1);

output = ScopeData.signals.values(:,2);

Or plot it directly using:

plot(ScopeData.time,ScopeData.signals.values)

- In addition, it is possible to save the data for later processing by writing:

save record_name ScopeData

And retrieving it back to Matlab either by double clicking the saved file or writing:

load('record_name.mat')

Note that you may notice some oscillation at constant voltage, that is due to non-linearity of the friction. If you measure the phenomena you may notice that its frequency is the same as the rotation angle frequency.

For the Report:

a. Present a plot using a figure from the scope simulation
b. Include a plot generated in the Matlab environment, using the ScopeData variable. Don’t forget to include legend, Title, Lables and Grid to the plot. You can check how to add this by typing “help plot” in the Matlab environment.
c. Write the max velocity of the motor (at 12V, -12V)

## Coulomb friction

We will begin our analysis by identifying the Coulomb friction within the system. Coulomb friction, often referred to as 'dry friction,' is a constant magnitude friction that opposes motion and is independent of the relative velocity between surfaces. In the context of a brushed DC motor, this phenomenon manifests as the Dead-Zone. The Dead-Zone is a region in which the motor doesn’t produce any movement even though a voltage is applied. This is primarily because the applied voltage or torque is not sufficient to overcome the inherent static friction of the system. It's crucial to identify and compensate for this Dead-Zone to ensure smooth operation and accurate control of the motor, particularly during its startup and low-speed operations

- Using the same “HexaMotor_MotorTest.slx” Simulink model. Find the minimum voltage values required to start the motor motion. You can change the slider range if you wish to use it to find the minimal values.

You can push the motor a bit with your hand and try to find the least resistance angle. (due to the non-linearity in the friction mentioned earlier).

- Write those values for next section.

## Step response modeling

In this section we will use the bump test to estimate the system`s transfer function. We will use in two methods, one with initial voltage 0, and the other with initial voltage of 2 volts.

- Open the “HexaMotor_System_Identification.slx” Simulink model. Make sure the switch is set to step input.
- Update the Motor Friction Preamp gains with the values found in the previous section.
- Adjust the step values to step at 1 second, from initial 0-volt to 7-volt step, update the Stop time to 5 seconds and record the response.
- Run the experiment again this time with a step from initial 2-volt to 9-volt step. Record the response.


Figure 10 Simulink model : HexaMotor_System_Identification.slx”

For the Report:

a. Find the transfer function from both experiments recording using the first order approximation. If the difference is more than 10% check your calculations. Remember that the step size is 7 volts. And in the second experiment the initial angular velocity isn`t zero. Consider in which cases it is preferred to perform one or the other.
b. Create a plot in Matlab which contains a step response from 0 volts to 7 volts from the recordings and as a simulation using the step function in Matlab for the identified transfer function.

Hint: Use the following commands to simulate a step response similar to the experiment. Don’t forget to include title. Legend etc. to the plot.

% T Is the calculated transfer function

plot(ScopeData.time,ScopeData.signals.values)

hold on

plot(ScopeData.time+1,step(T,ScopeData.time)*7)

## Frequency response modeling

In this section we will generate a bode plot for the system and derive the transfer function using its frequency response to several input frequencies.

- Using the same “HexaMotor_System_Identification.slx” Simulink model. Move the switch to a sin input. And update the stop time to inf.
- Update the parameters of the input Amplitude:7 Frequency (rad/sec): 1 rad/sec and run the model, notice the system response.
- Measure the time delay and magnitude of the response.


Figure 11 Sine wave response - Live scope

For the Report:

a. Fill up the following table make sure to record at list 7 frequencies at the range of [0..30] rad/sec

Hint: you can change the frequencies while the model is running and print to figure while it runs. Gain=(Max velocity)/(Input Amplitude) , ω=0 can be calculated from the step response.

Frequency (Rad/sec) | Input Amplitude (V) | Max velocity (rad/s) | Time Delay (s) | Gain (rad/s/v) | Gain(dB). | Phase (degree)
0
…..
30

b. Approximate the ω_b by evaluating the frequency at which the amplitude |G(ω_b )|=1/(√2)|G(0)| . store the response for that frequency and calculate the time constant τ . How close it is to the τ calculated from the step response? Which method will give a more precise result?

Hint: Pre lab question 2.2 c.

c. Plot a bode plot using the data from the table.

Hint: use the following Matlab commands:

% Create a frequency response data object

% units: amplitudes [rad/s/v], frequencies [Rad/sec], phases [Deg].

freq_data = idfrd(amplitudes, frequencies, 0);

% Estimate transfer function (first order system)

sys = tfest(freq_data, 1)

% plot bode like plot, with the added points

s=tf('s');

w = logspace(-1,2,100);

% sys∙1/(0.05s+1) - sets a second order system with a low pass filter at τ=0.05 , but a more proper % method would be to estimate sys as a second order system with a known pole of the filter

[mag,phase] = bode(sys*(1/(0.05*s+1)),w);

figure(1);

subplot(2,1,1)

semilogx(w,20*log10(squeeze(mag)))

hold on

semilogx(frequencies, 20*log10(amplitudes), '*');

subplot(2,1,2)

semilogx(w,squeeze(phase))

hold on

semilogx(frequencies,phases)

Example Plot


Figure 12 Bode plot containing simulated and measured data

Note: The resulting plot contains a phase up to -180 degrees due to the presence of a low pass filter for the velocity measurements at τ=0.05

d. How close the transfer function derived from the bode estimation to the one found from the step response. What do you think, which one is more precise? which was faster to achieve?

## PID controller

In velocity control setups for motors, a PI (Proportional-Integral) controller is commonly used. While the PID controller includes all three terms — Proportional, Integral, and Derivative — the PI controller only uses the Proportional and Integral terms. The reason for excluding the Derivative term in velocity control is due to the nature of the application. In many motor control scenarios, the Derivative term can introduce noise or lead to excessive sensitivity to rapid changes. Given the objectives of velocity control, the PI controller strikes a balance between performance and stability, delivering smooth and consistent motor speed without the potential drawbacks of the Derivative term.

## 3.1.1. Steady state error

We will start by measuring the steady-state error of the angular velocity using a simple proportional gain of 1 and comparing the results to a simulated system based on the model identified in previous sections.

- Open the “HexaMotor_Velocity_Control.slx” Simulink model.
- Update the Motor Friction Preamp gains with the values found in the first section.
- Adjust the square wave Pulse Generator a period of 4 seconds pulse width of 2 seconds and delay of 1 second, set the amplitude to 15 rad/s and update the Stop time of the simulation to 7 seconds.
- Update the PI controller to proportional gain Kp=1 and integral gain Ki=0
- Run the experiment.

Figure 13 Simulink model : HexaMotor_Velocity_Control.slx


For the Report:

a. Compare the steady state error to the theoretical one
b. Using the recording of the experiments create a plot in Matlab containing the response from the experiment and simulated results from the plant found in section 3.4. You may notice that the responses aren`t exactly the same, that is due to non-linearity’s in the actual setup and to the presence of the low pass filter for the velocity measurement. You may also add simulated results including the low pass filter for comparison. ( LPF(s)=1/(0.05s+1) ).

Hint: use the following Matlab commands: (do not forget to update the transfer function and add grid, axis labels, title to the plot).

% Generate plots from recordings and simulated transfer function

s=tf('s');

G = 2.5/(0.1*s+1); % update the estimated transfer function

LPF = 1/(0.05*s+1);

figure(1)

plot(ScopeData.time,ScopeData.signals.values(:,1))

hold on

plot(ScopeData.time,ScopeData.signals.values(:,2),'.');

[y,t] = lsim(G/(1+G),ScopeData.signals.values(:,1),ScopeData.time);

plot(t,y);

[y,t] = lsim(G*LPF/(1+G*LPF),ScopeData.signals.values(:,1),ScopeData.time);

plot(t,y);


Figure 14 Square wave response, actual system and simulated models

## 3.1.2. PI Controller manual tuning

In this section, we will discuss how to tune the parameters of a PI (Proportional-Integral) controller to achieve a desired response.

- Begin by setting the integral gain to 0 and adjust the proportional gain within the range of [0 to 2] until the response exhibits a slight overshoot or reaches the desired rise time.
- Introduce the integral gain to minimize the steady-state error and ensure the response meets the desired peak time, overshoot, and settling requirements. If needed, decrease the proportional gain.
- Fine-tune both the Proportional and Integral gains as required to fulfill the design specifications.

Adjust the parameter to get the following control specifications:

0.3s>T_(PeakTime) >0.15s , T_(Settling) <0.5s , Overshoot<15%

Hint: you can set the Stop time of the simulation to ‘inf’ while tunning the parameters.

For the Report:

a. Plot the response of the system, with the simulated theoretical model. Mark the important criteria and calculate overshoot of the system.


Figure 15 Square wave response, actual system and simulated models

Note: The resulting simulated plot differs slightly from the actual response. This difference arises because the simulation does not account for all the non-linearities of the actual setup. Additionally, we approximated the system as a first-order system, but ideally, it should have been estimated as a second-order system due to the presence of the low-pass filter, whose pole is not significantly distant from the motor's pole.

Don't forget to turn off the system at the end of the experiment using the button at the back.

# 4. Appendix

Github Page: https://github.com/TALs-Education/HexaMotor

## DC Motor

This gearmotor consists of a low-power, 12 V brushed DC motor combined with a 20.4:1 metal spur gearbox, and it has an integrated 48 CPR quadrature encoder on the motor shaft, which provides 979.62 counts per revolution of the gearbox’s output shaft.

Product page: https://www.pololu.com/product/4883

Data Sheet: https://www.pololu.com/file/0J1829/pololu-25d-metal-gearmotors.pdf

## Arduino boards

The MKR Motor Carrier is an MKR add-on board designed to control servo, DC, and stepper motors. The Carrier can also be used to connect other actuators and sensors via a series of 3-pin male headers.

MKR Zero: https://docs.arduino.cc/hardware/mkr-zero

MKR Motor Carrier: https://store-usa.arduino.cc/products/arduino-mkr-motor-carrier

## Simulink Support package

With MATLAB and Simulink Support Packages for Arduino® hardware, you can use MATLAB and Simulink to interactively communicate with your Arduino. Simulink also enables you to perform model deployment for standalone operations on Arduino boards.

MathWorks: https://www.mathworks.com/hardware-support/arduino.html

## 3D Model – Fusion360

The setup is design in Fusion360 as an open source project, for educational purposes. Available at:

Fusion360: https://a360.co/3TU1BYP

The Iby and Aladar Fleischman Faculty of Engineering Tel Aviv University

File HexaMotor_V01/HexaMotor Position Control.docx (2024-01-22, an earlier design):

# Position Control

# HexaMotor


Experiment objectives:

• Introduction to second order systems.

• Coulomb Friction identification and handling.

• System identification using position close loop step reponse.

• System identification using position close loop frequency reponse.

• Position control implementation based on second order system modeling.

• Lead-Lag compensator controller design and implementation.

• Force FeedForward example - compliant motor control.

# 1. Introduction

In the field of motor control, mastering both velocity and position control is essential for a wide range of applications. While the previous lab experiment delved into the nuances of velocity control and the fundamentals of a DC motor, this experiment pivots to emphasize position control. Position control, vital for accurate maneuvering and precise positioning of mechanisms, demands its own unique approach. This experiment outlines objectives ranging from system identification using step and frequency responses to the design and actual implementation of control strategies.

## First order approximation

While in the previous experiment the full equations of the DC motor were presented and the first-order approximation was derived, in this experiment we will contrinue working with the first-order approximation of the DC motor.

First-Order Transfer Function:

  1.1 G(s)=(K_T)/((RJ)s+(BR+K_T K_b )) ; G(s)=(K_m)/(τs+1)

## Coulomb friction

Recall from the previous experiment that Coulomb friction, which remains constant irrespective of motor speed, contributes to system non-linearity and can pose challenges in control implementation, particularly at low speeds. We identified this friction by applying a controlled voltage to the DC motor, observing the threshold voltage initiating rotation.

## Second order systems

When discussing control systems, a second order system is frequently encountered. It can be described by the standard second-order transfer function:

  1.2 T(s)=K/(s^2 +2ζω_n s+ω_n^2)

Where:

K – is the system static gain.

ω_n – is the undamped natural frequency.

ζ – is the damping ratio.

The system's response is primarily characterized by its damping ratio ζ and natural frequency ω_n

Several performance metrics can be derived from the above standard form:

Percent Overshoot (%OS):

It defines the amount by which the transient response exceeds the steady-state value. For a step response, the percent overshoot is given by: OS=100e^((-πζ)/(√(1- ζ^2))) It should be noted that overshoot occurs only when ζ <1 (underdamped case).

Rise Time (Tr):

The time it takes for the response to rise from 10% to 90% of its final value for an underdamped system. While there's no direct closed-form formula, for many systems with a damping ratio between 0.4 and 0.7, the rise time is approximately: T_r ≈ 1.8/(ω_n)

Settling Time (Ts):

The time for the system response to stay within a certain percentage (usually 2% or 5%) of its final value. It's given by T_s ≈ 4/(ζω_n) for a 2% settling time.

Peak Time (Tp):

The time it takes for the response to reach its first peak. For an underdamped system: T_p = π/(ω_d) where ω_d = ω_n √(1-ζ^2) is the damped frequency.

Natural Frequency ( ω_n ):

It's the frequency at which the system would oscillate if there were no damping (i.e., ζ=0).

## Root Locus

The essence of the root locus lies in its depiction of system dynamics. The locations of the closed-loop poles directly influence the transient response characteristics of the system. By examining the root locus, engineers can predict how changes to the system gain will impact crucial performance metrics such as overshoot, settling time, and oscillation frequency.

The foundation of the root locus method is built on two fundamental principles:

- Magnitude Criterion: At any point on the root locus, the product of the magnitudes of the vectors from all open-loop zeros to that point divided by the product of the magnitudes of vectors from all open-loop poles to that point is equal to 1 (or the gain at that point).
- Angle Criterion: For a point to lie on the root locus, the sum of angles from all open-loop zeros and poles to that point must equal an odd multiple of 180°.

Armed with these criteria, control system engineers can sketch the root locus and use it to select appropriate gains that yield desired closed-loop behavior. Not only does the root locus offer insights into system stability (since poles in the right half of the complex plane denote instability), but it also aids in shaping the system response to meet specified design criteria.

## PID controller

As previously discussed in our prior experimentation, the PID controller is a predominant feedback control algorithm extensively employed in industrial applications due to its efficiacy across diverse scenarios and its systematic tuning methodology.

  1.3 u(t)=K_p e(t)+K_i ∫ e(t)dt+K_d (de(t))/(dt)

The PID controller is characterized by three fundamental components:

Proportional (P): This component yields a control action that is directly proportional to the instantaneous error. The magnitude of this response is governed by the proportional gain

Integral (I): Concerned with the aggregation of error over time, this action aims to nullify any persistent steady-state error.

Derivative (D): This term offers a control action based on the rate of error change, effectively anticipating potential future errors and generating a preemptive control response. In practical applications, a distant pole is introduced to filter out system noise. In our case, the derivative element is filtered by a first-order pole set at half the sampling frequency.

## Lead-Lag Compensator

Lead and lag compensators are essential tools in control theory, particularly in the design of feedback control systems to meet transient and steady-state response specifications:

Lag Compensator: The general transfer function for a lag compensator can be described as:

  1.4 G_(Lag) = (1+τs)/(1+aτs)

Where τ is the time constant and a>1.

Purpose: The primary purpose of a lag compensator is to improve the steady-state response of the system. This is done by adding a pole and a zero to the system. Since the zero is closer to the origin than the pole, the compensator will have a magnitude less than one for most frequencies, thereby reducing the gain of the system and the steady-state error.

Placement: The zero is placed to the left of the pole. The distance between them determines the magnitude of the phase boost, but a lag compensator will not introduce a significant phase lead.

Drawbacks: Lag compensators generally degrade the transient response because they tend to reduce the system bandwidth.


Figure 1 Lag Compensator plot using LeadLad.m scrip

Lead Compensator: The general transfer function for a lead compensator can be described as:

  1.5 G_(Lead) = (1+aτs)/(1+τs)

Where τ is the time constant and a>1

Purpose: The primary purpose of a lead compensator is to improve the transient response of the system. By placing a pole and a zero in the left half plane, it introduces phase lead to the system, which can be used to reshape the root locus or push the closed-loop poles to desired locations.

Placement: The zero is placed to the right of the pole, introducing phase lead in the frequency range of interest. The amount of phase lead is determined by the distance between the pole and zero and their proximity to the imaginary axis.

Drawbacks: Because of the introduced phase lead, a lead compensator also increases the gain in some frequency range. This can make the steady-state error worse.


Figure 2 Lead Compensator plot using LeadLad.m scrip

Design Considerations:

Lag: When using a lag compensator, the goal is often to place the pole and zero sufficiently far from the imaginary axis, so they don't affect the transient response. You place the zero so that the magnitude of the system is unchanged at the crossover frequency.

Lead: When designing with a lead compensator, the goal is often to add enough phase lead to achieve desired transient characteristics without pushing the gain crossover frequency too high.

In practice, combining both lead and lag compensators can offer an optimal balance between steady-state and transient performance in many systems.

Graphical approach for Lead Lag design:

Run the "LeadLag.m"

- The script "LeadLag.m" generates plots associated with the lead-lag compensator design. This includes various curves representing different amounts of phase lead and the corresponding gains for different values of a (since a lead compensator's behavior is determined by its zero and pole locations, which are in turn determined by the parameter a and the time constant τ).

Open-Loop Bode Plot:

- Start by plotting the open-loop Bode plot of the system. From this plot, you'll identify the current crossover frequency ω_c and the existing phase margin.

Determine Required Phase Boost:

- Based on system specifications or desired closed-loop performance, determine how much additional phase you want to introduce.

Iterative Process for Design:

- Use the provided lead graph (generated by the script) to identify a point that provides the necessary phase boost.
- From the corresponding gain graph, note the gain added due to the lead compensator.
- This added gain will shift ω_c in the open-loop Bode plot.
- Now, with this new ω_c the phase requirements might be slightly different. So, you may need to iterate this process to ensure that the final selected values of phase and gain boosts provide the desired performance.

Calculate the Lead Compensator:

- Using the relationship and the equation provided: G_(Lead) (s)=(1+aτs)/(1+τs)
- And given: τ= u/(ω_c) Where:
- τ is the time constant of the lead compensator.
- a is the gain boost and defines the curve.
- u is the specific point on the curve/graph which dictates the amount of phase lead and gain boost introduced.
- ω_c is the new crossover frequency after introducing the compensator.

Implement and Test:

- Once the lead compensator parameters are determined, you can then apply them to the system and validate if the system's response matches your design specifications. You may also need to iterate the design process if the initial compensator doesn't provide the desired results.

This process essentially allows you to design a lead compensator using graphical methods, taking advantage of the insight provided by Bode plots and the relationships between phase lead, gain boost, and compensator parameters.

# 2. Pre Lab
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

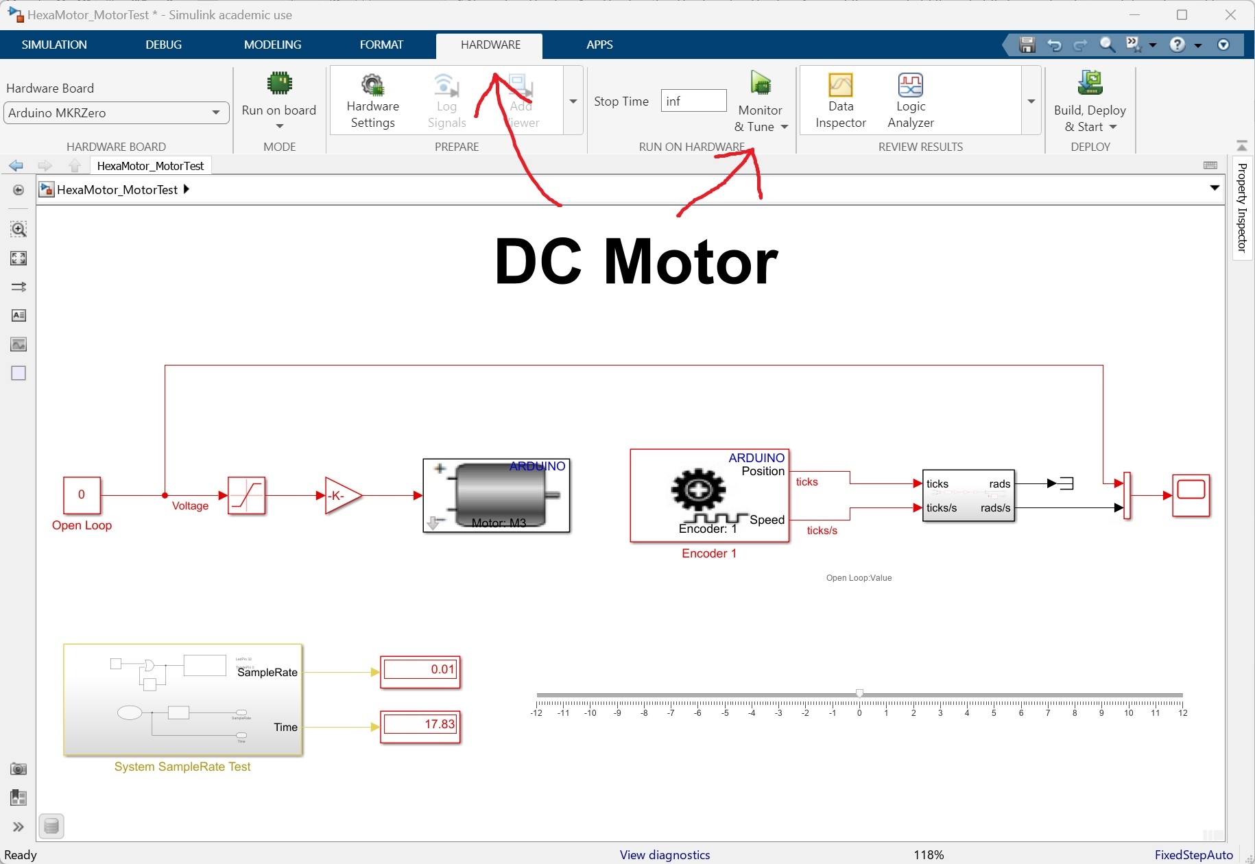
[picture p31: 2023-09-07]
Images/Simulink.jpg

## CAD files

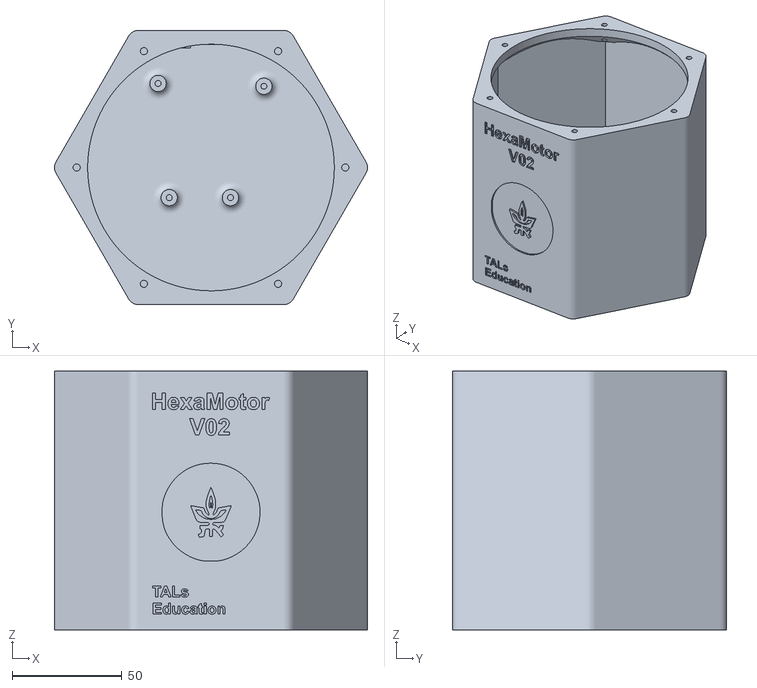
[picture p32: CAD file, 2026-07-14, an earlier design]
HexaMotor_V02/STL/Main Frame.stl
142.7 x 125.0 x 118.0

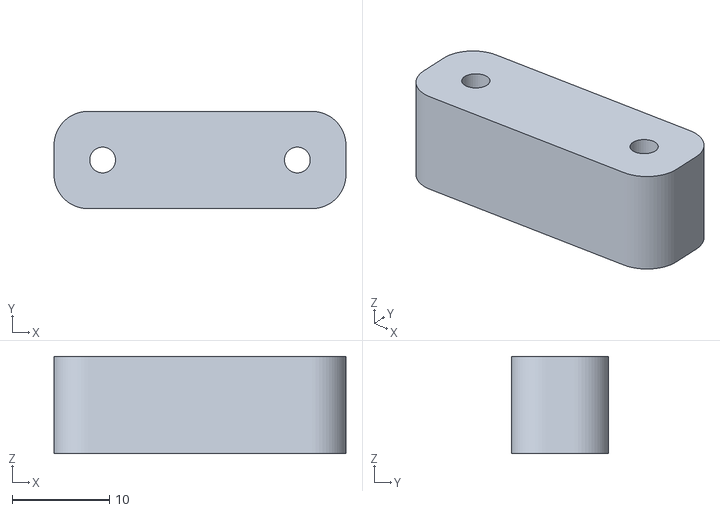
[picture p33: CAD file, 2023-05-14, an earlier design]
HexaMotor_V01/STL/Bumper.stl
30.0 x 10.0 x 10.0

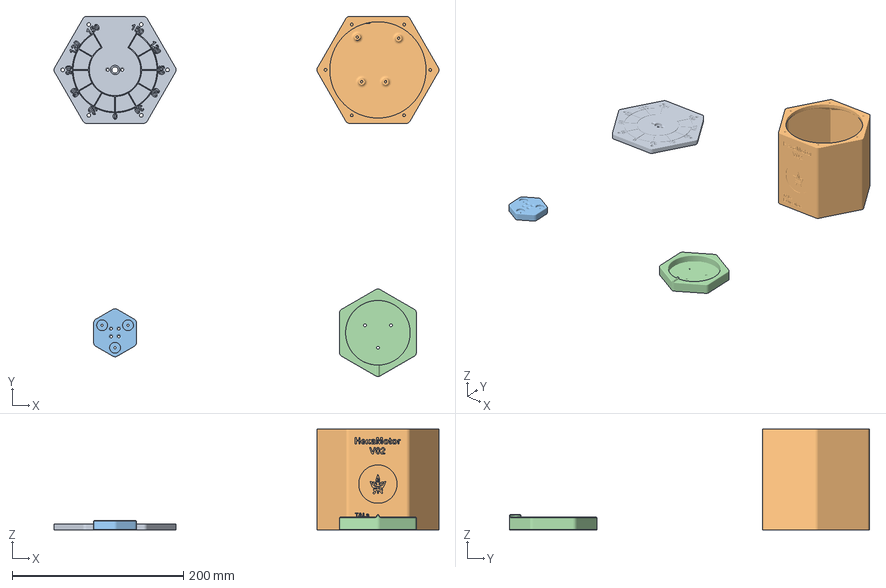
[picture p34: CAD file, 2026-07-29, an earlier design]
HexaMotor_V02/STL/HexaMotorV02.3mf
449.9 x 420.9 x 118.0 mm
Frame Cover.stl
Main Frame.stl
Magnetic Adapter.stl
Rotating Mass.stl

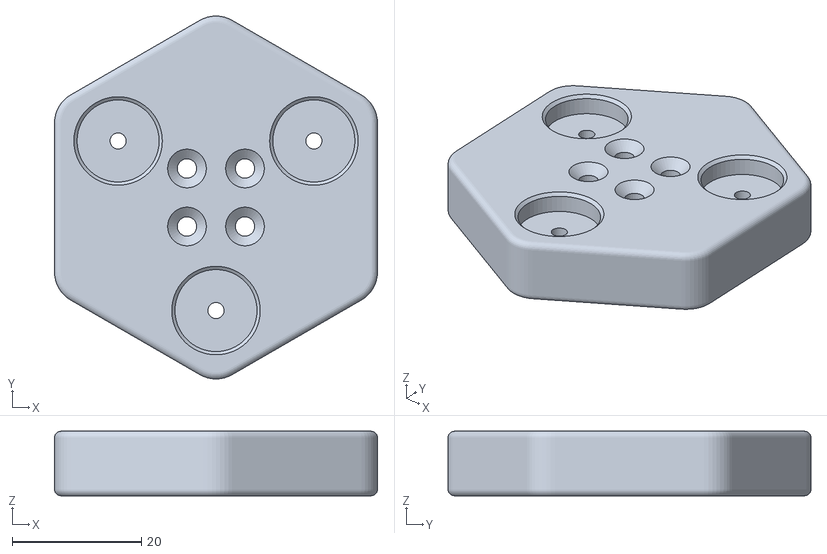
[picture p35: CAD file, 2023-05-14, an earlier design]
HexaMotor_V01/STL/Magnetic Adapter.stl
50.0 x 56.2 x 10.0

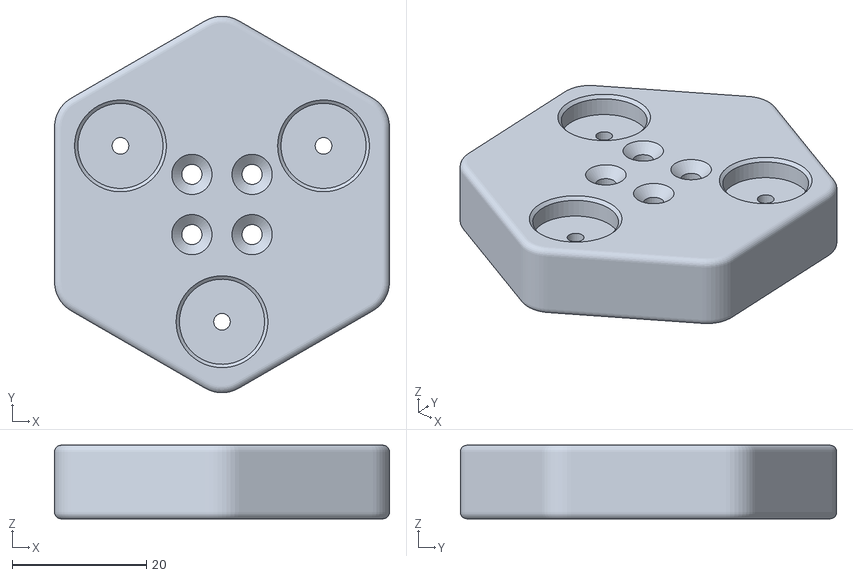
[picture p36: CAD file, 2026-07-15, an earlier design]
HexaMotor_V02/STL/Magnetic Adapter.stl
50.0 x 56.2 x 11.0

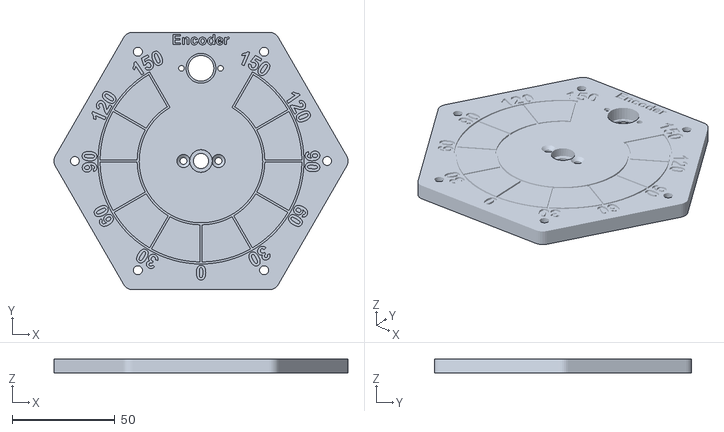
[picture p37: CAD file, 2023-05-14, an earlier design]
HexaMotor_V01/STL/Frame Cover.stl
142.7 x 125.0 x 7.00

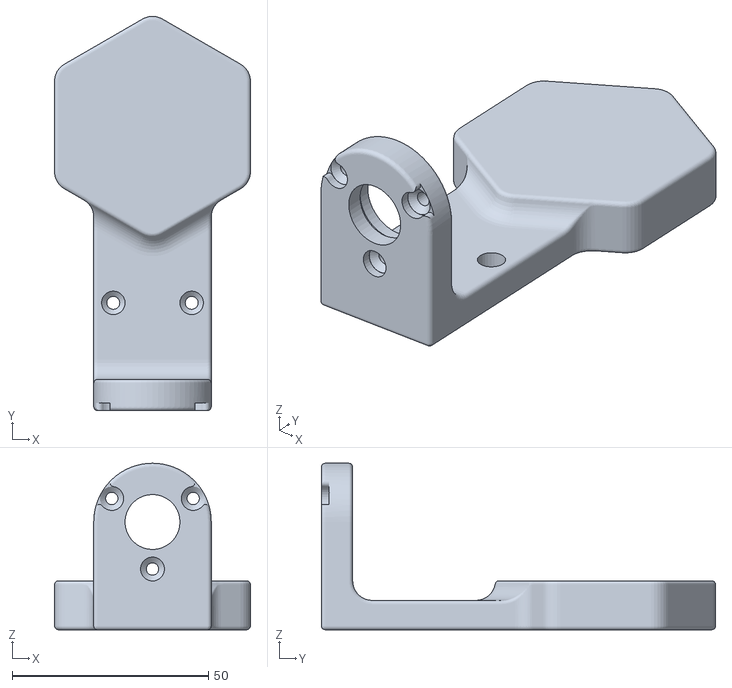
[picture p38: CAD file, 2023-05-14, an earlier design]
HexaMotor_V01/STL/Pendulum.stl
50.0 x 100.6 x 42.5

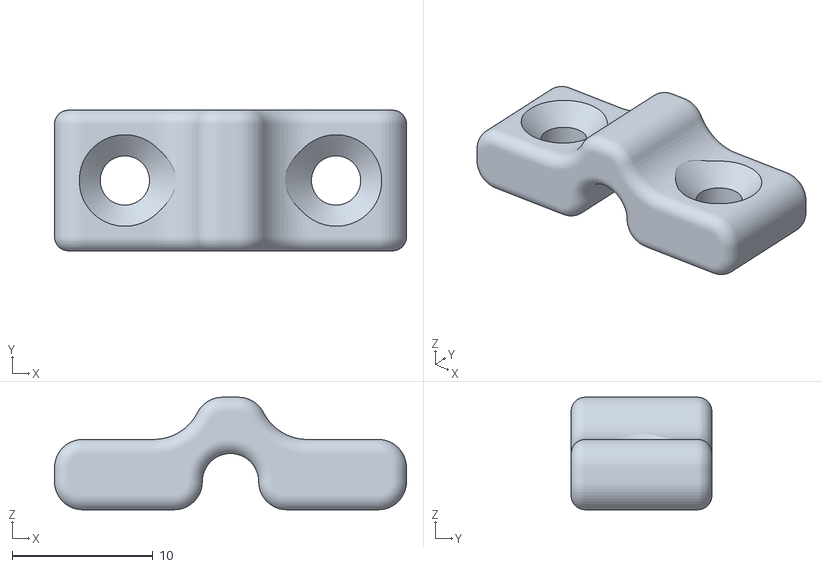
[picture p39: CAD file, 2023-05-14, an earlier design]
HexaMotor_V01/STL/ForceRodWireClamp.stl
25.0 x 10.0 x 8.00

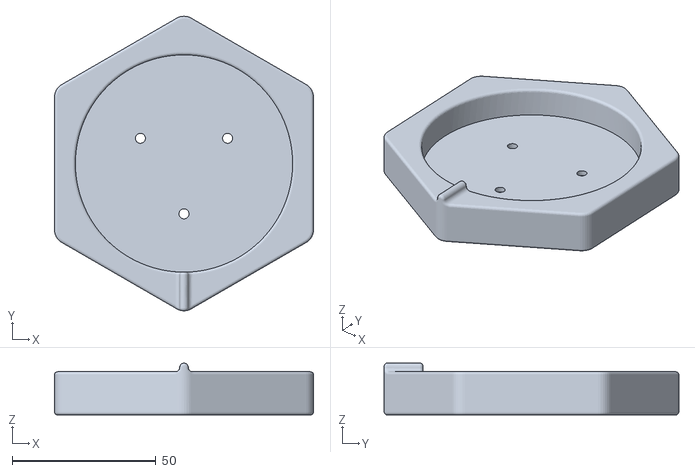
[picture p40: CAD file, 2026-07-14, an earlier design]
HexaMotor_V02/STL/Rotating Mass.stl
90.0 x 102.4 x 18.0

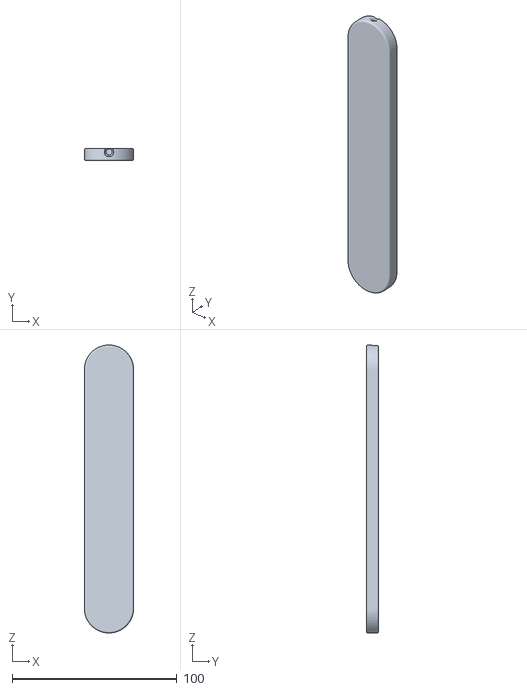
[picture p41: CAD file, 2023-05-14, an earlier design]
HexaMotor_V01/STL/Pendulum Rod.stl
30.0 x 7.50 x 175.0

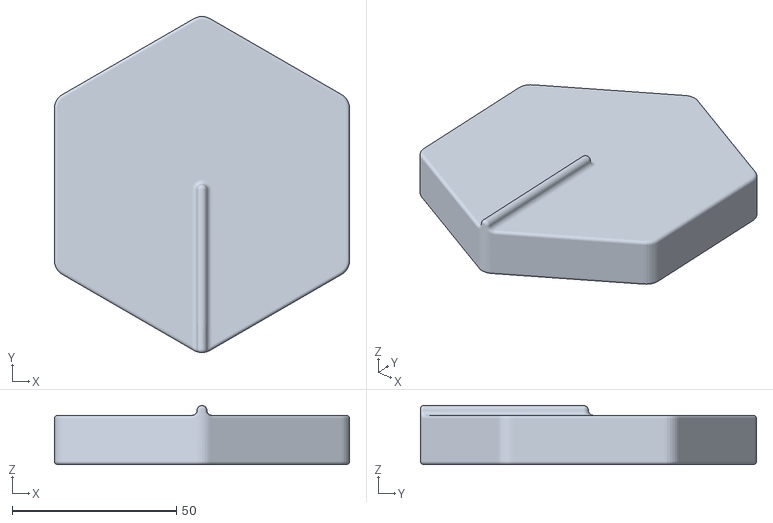
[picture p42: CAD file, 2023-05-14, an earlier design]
HexaMotor_V01/STL/Rotating Mass.stl
90.0 x 102.4 x 18.0

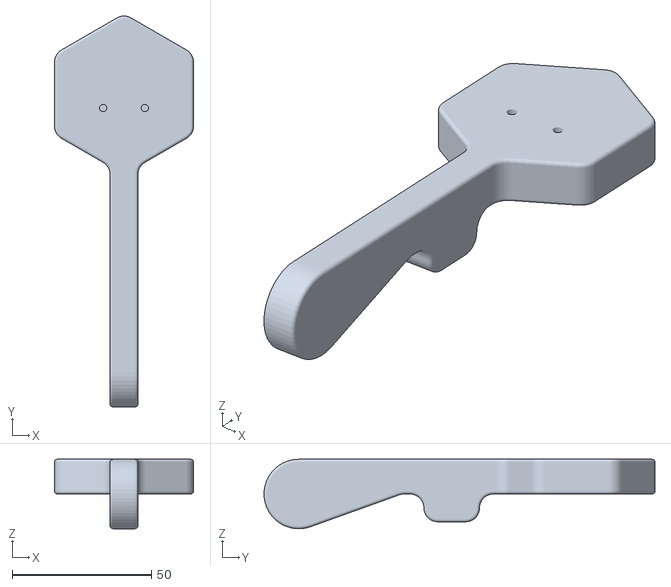
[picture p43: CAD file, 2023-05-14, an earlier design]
HexaMotor_V01/STL/ForceRod.stl
50.0 x 140.6 x 25.0

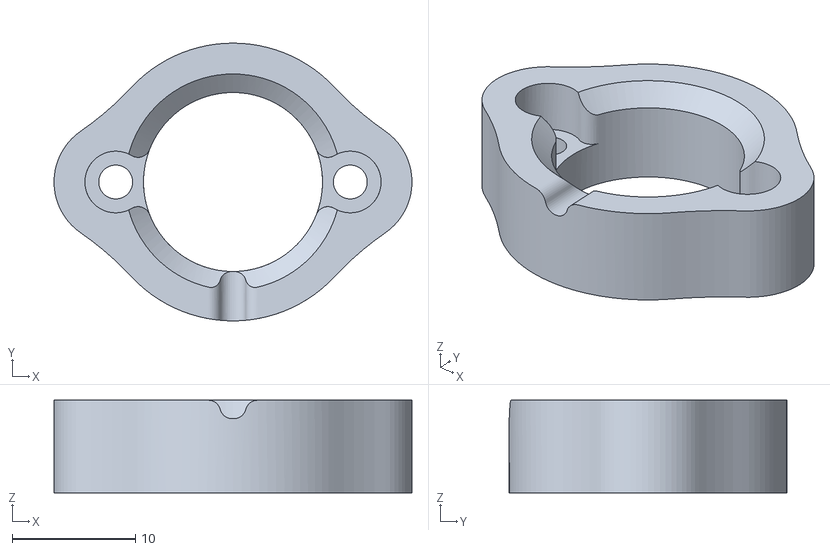
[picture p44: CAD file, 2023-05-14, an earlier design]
HexaMotor_V01/STL/mDinProtector.stl
29.0 x 22.5 x 7.50

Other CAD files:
HexaMotor_V01/STL/Main Frame.stl
HexaMotor_V02/STL/Frame Cover.stl

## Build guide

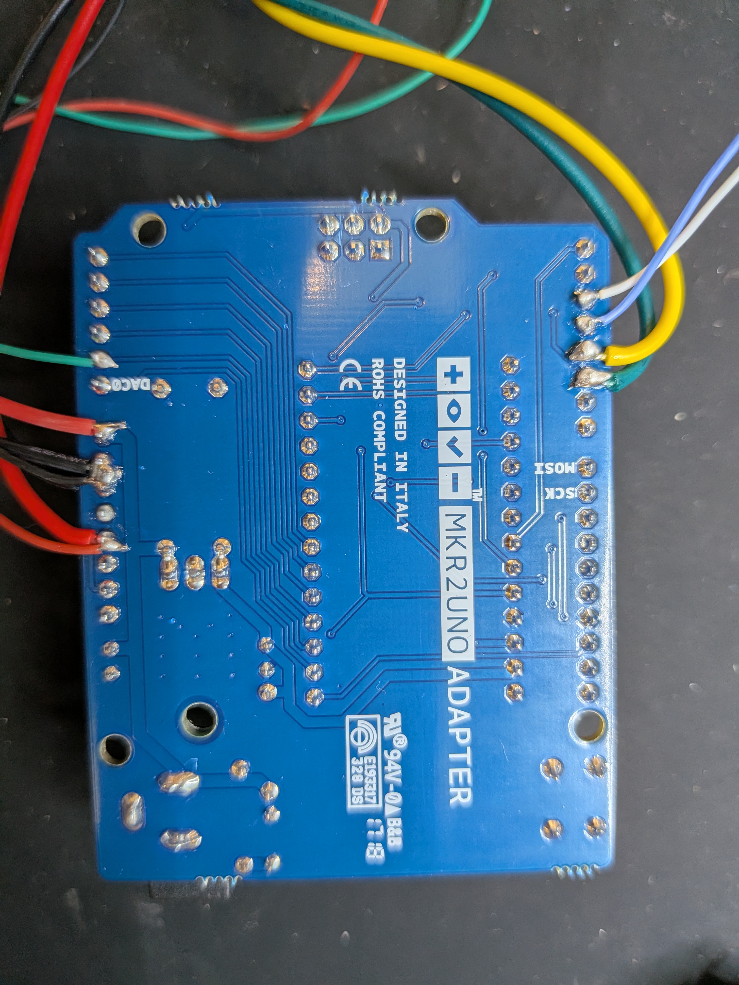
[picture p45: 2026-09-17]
Images/Assembly/V02/UnoMKRShieldV02_2.jpg

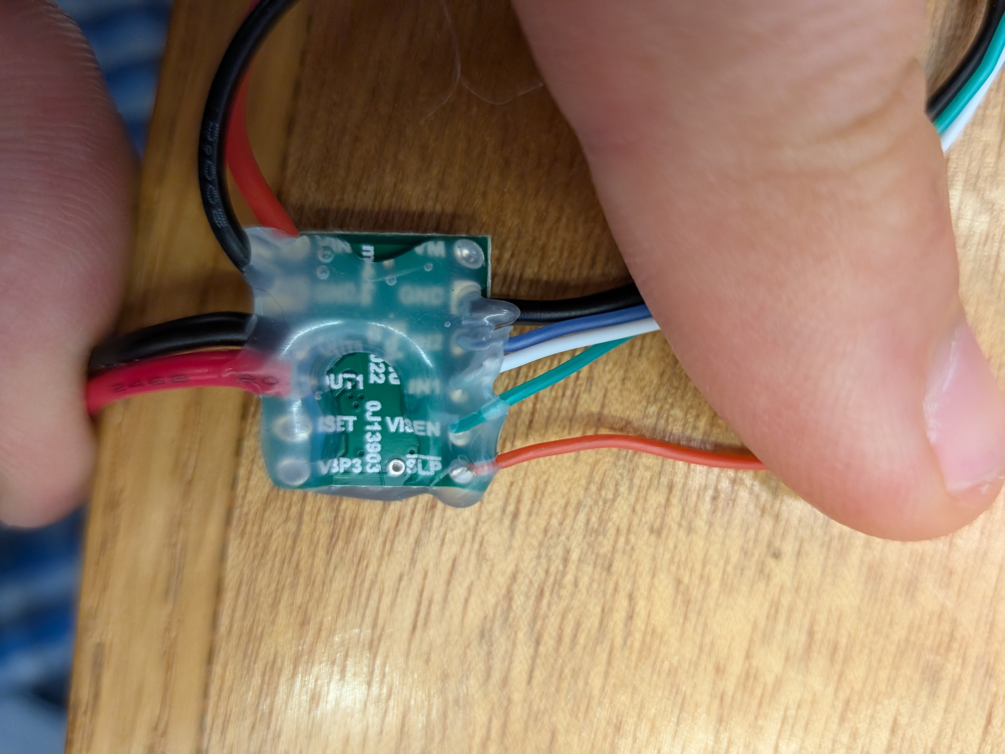
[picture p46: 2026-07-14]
Images/Assembly/V02/MotorDriverV02.jpg

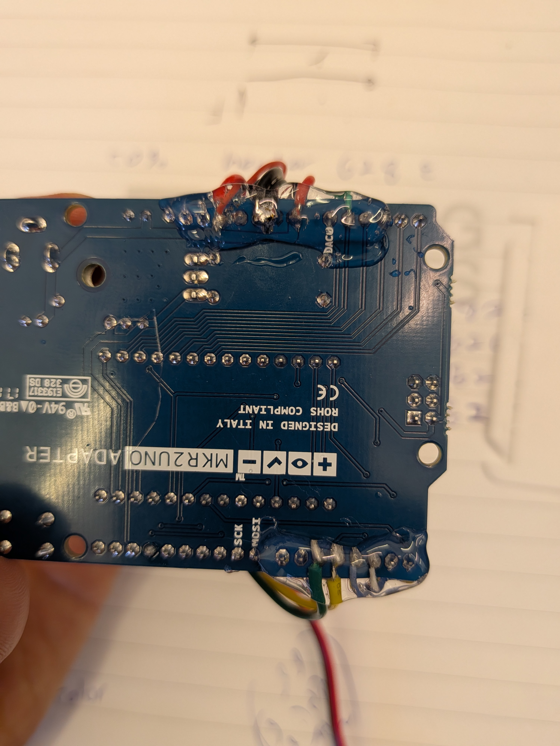
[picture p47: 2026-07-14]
Images/Assembly/V02/UnoMKRShieldV02.jpg

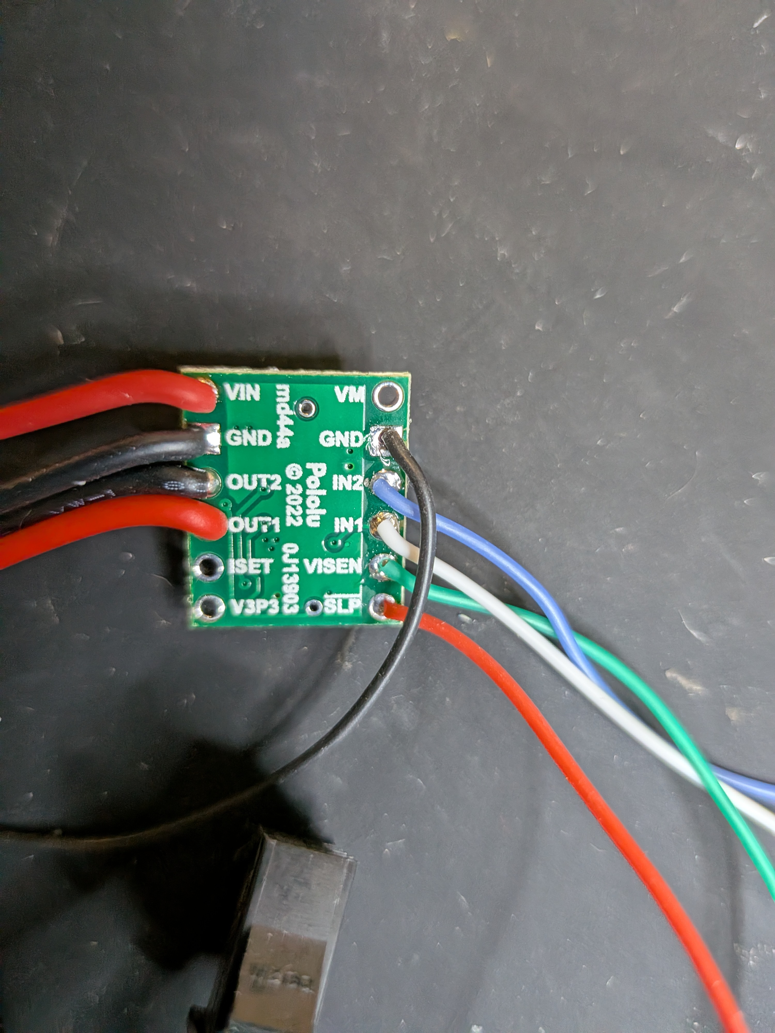
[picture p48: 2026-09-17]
Images/Assembly/V02/MotorDriverV02_2.jpg

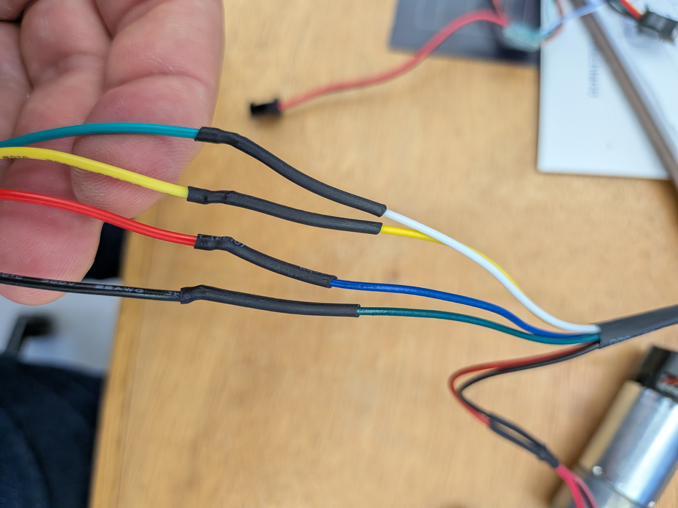
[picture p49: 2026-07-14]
Images/Assembly/V02/MotorEncoderConnector_V02.jpg

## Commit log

2023-09-12 velocity control manual
2026-07-13 updated paths
    [Bumper.stl, ForceRod.stl, ForceRodWireClamp.stl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]
2026-07-14 file arangment stl v02 addition
    [Frame Cover.stl, Magnetic Adapter.stl, Main Frame.stl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]
2026-07-15 Update Magnetic Adapter.stl
    [Magnetic Adapter.stl]
2026-09-22 added 250Hz models
2026-10-05 added motor simulation
2026-10-28 motor control
